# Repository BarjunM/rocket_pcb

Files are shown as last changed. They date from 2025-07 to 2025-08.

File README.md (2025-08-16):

# Elytra: TVC Hobby Rocket Flight Computer

## Short Description

Elytra is a half-kilogram solid-fuel TVC hobby rocket flight computer. To develop a custom computer, the goal is to start as simple as possible and iterate through more and more detailed developments. The current version thus far incorporates working components including an ESP32, BMP280, and MPU6050 dev board and joins them all onto 1 single pcb.

## Why Make This Project?

The purpose of Elytra is to eventually explore self-landing rocket technology. In order to develop an autonomous rocket, the computer needs to be able to read input data regarding yaw, pitch, roll, acceleration, and elevation in order to actively adjust the direction of thrust and self-correct direction. Hence, the purpose of the flight computer is to actively control a thrust vectoring system via servos (TVC) based on input data from various telemetry sensors, including an accelerometer (mpu6050) and barometer (bmp280)

video demo: https://youtu.be/cWIUwfU-qWE

## Project Images

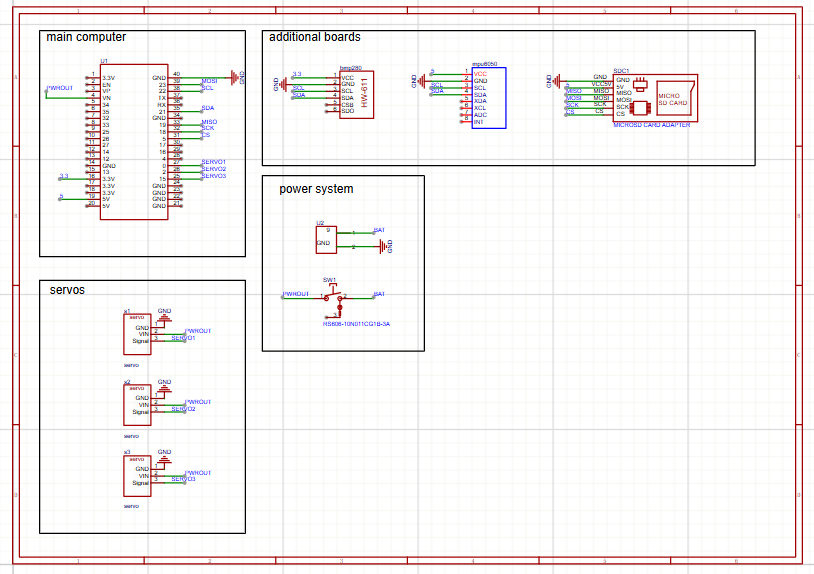
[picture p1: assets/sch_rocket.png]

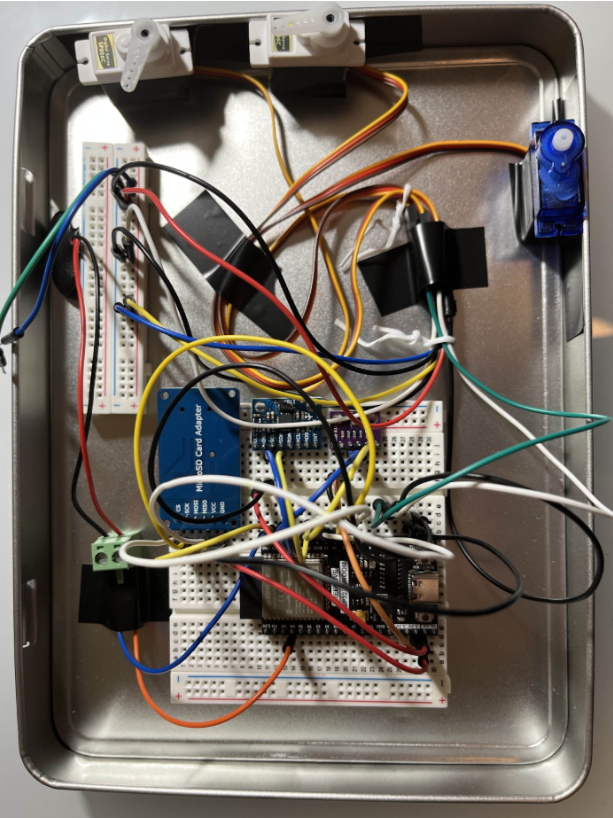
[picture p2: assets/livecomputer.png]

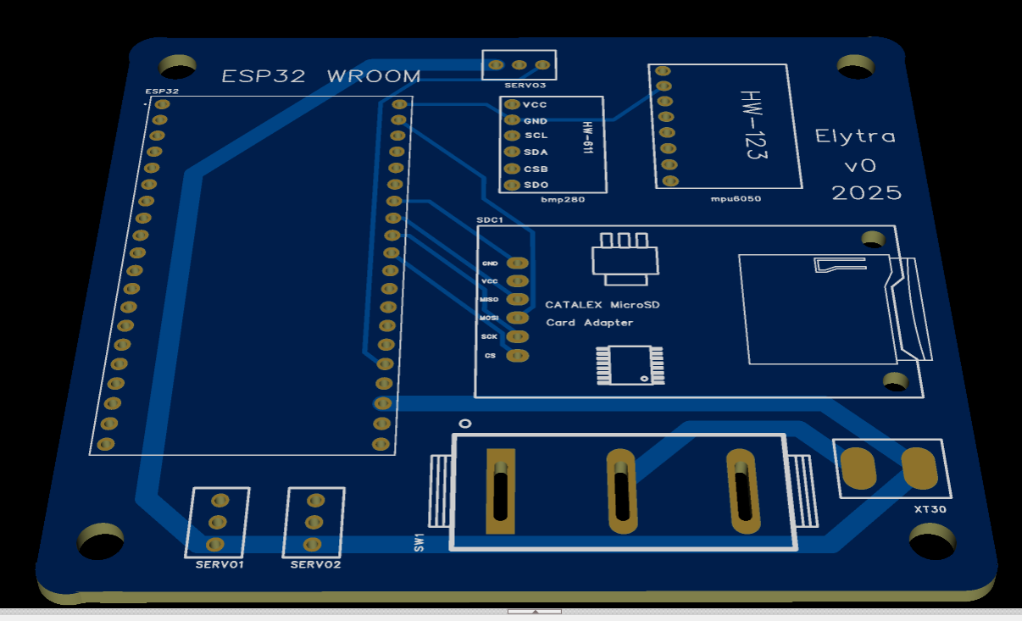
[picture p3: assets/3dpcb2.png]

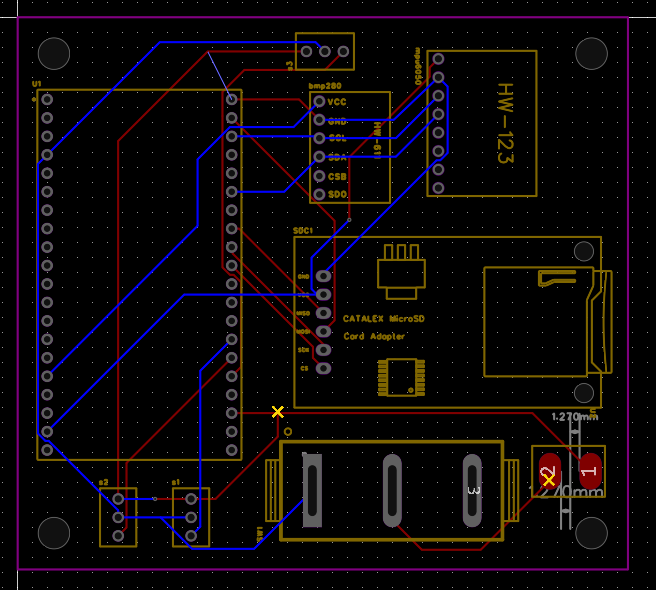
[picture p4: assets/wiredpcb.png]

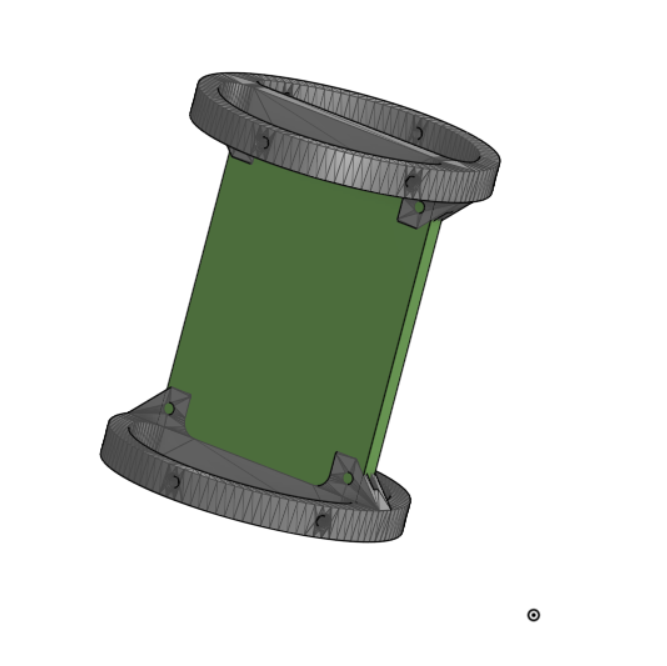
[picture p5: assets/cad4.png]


### Assembly & Test




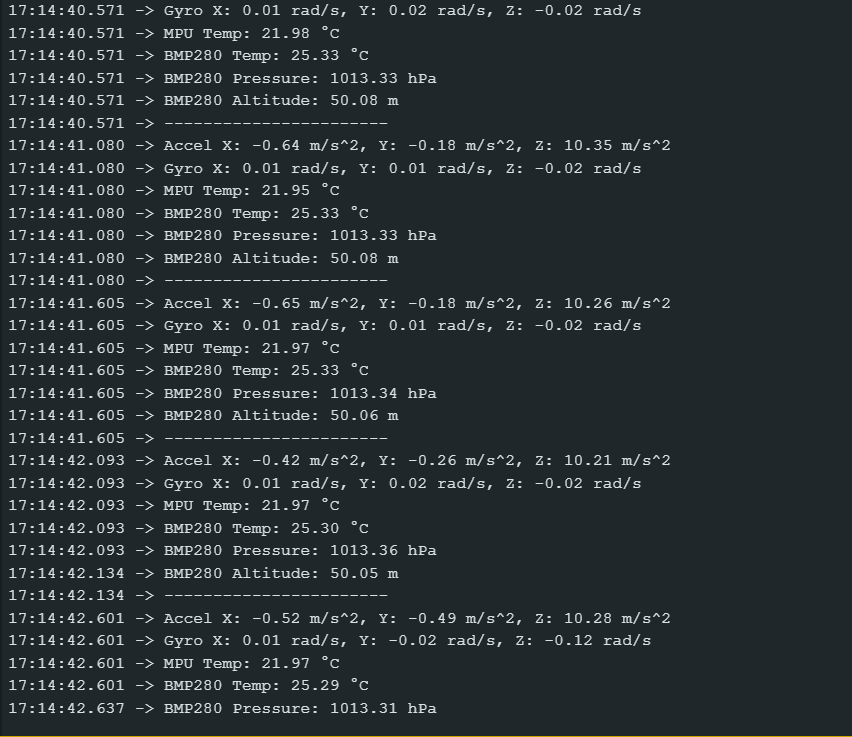
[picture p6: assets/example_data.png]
data


## BOM

| No. | Qty | Component / Comment | Supplier Part | Supplier | Unit Cost | Total Cost (+shipping) | Link |
|-----|-----|---|---|---|---|---|---|
| 1 | 5 | RS606-10N011CG1B-3A | C2885789 | LCSC | $0.67* | $3.35* | [JLCPCB](https://jlcpcb.com/partdetail/HCTL-RS606101N011CRB/C2885788) |
| 2 | 1 | MPU6050 Breakout (Accelerometer) | - | AliExpress | - | Already Owned | - |
| 3 | 1 | BMP280 Breakout (Barometer) | - | AliExpress | - | Already Owned | - |
| 4 | 1 | ESP32 WROOM (Microcontroller) | - | AliExpress | - | Already Owned | - |
| 5 | 1 | Micro SD Card Reader (Data Storage)  | - | AliExpress | - | Already Owned | - |
| 6 | 1 | Servos (Motor) | - | AliExpress | - | Already Owned | - |
| 7 | 1 | 3S LiPo (Battery) | - | AliExpress | - | Already Owned | - |
| 8 | 5 | 3S XT30 to 5V 5A (Buck Converter) | - | SpeedyFPV  | - | Already Owned | - |
| 9 | 5 | Custom PCB | - | JLCPCB | $2.92 | $14.60 + $27.72 shipping| - |

**Total Cost: $45.67** (excluding already owned components)

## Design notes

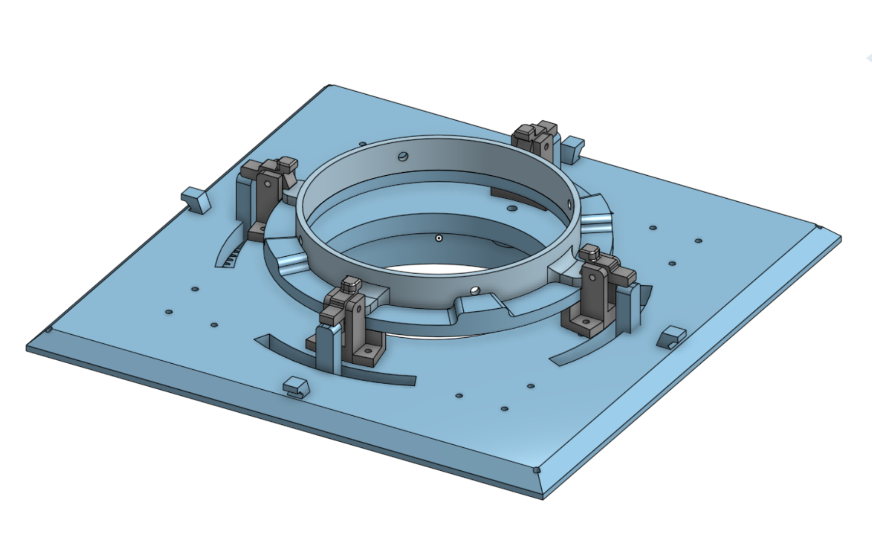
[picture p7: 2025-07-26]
assets/cad2.png

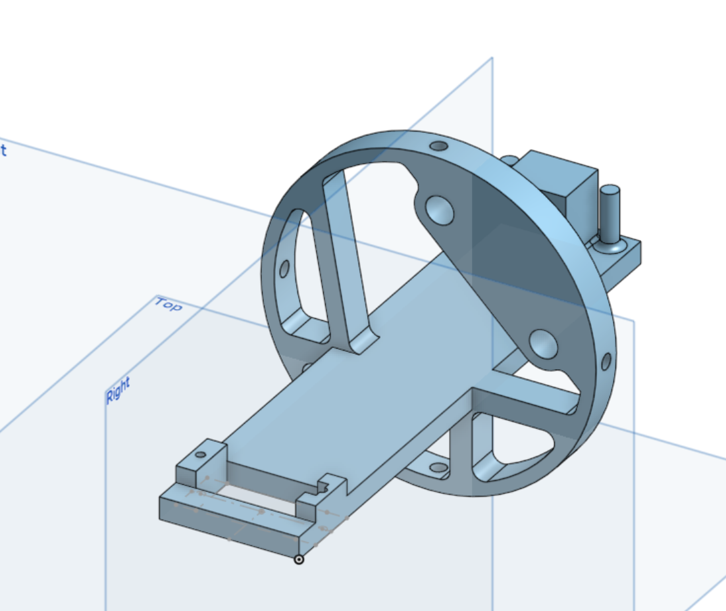
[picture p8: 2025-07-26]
assets/cad1.png

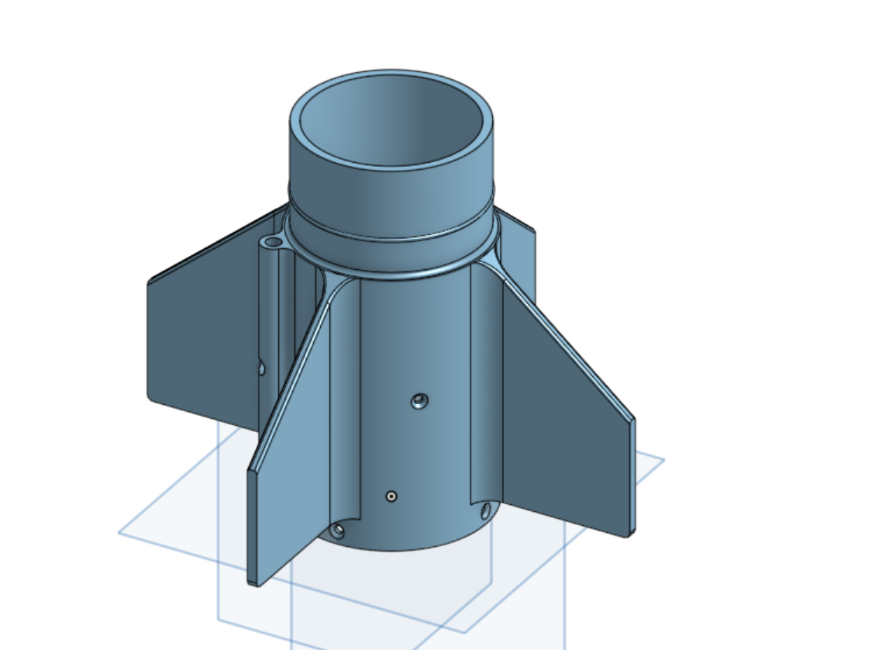
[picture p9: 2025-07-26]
assets/cad3.png

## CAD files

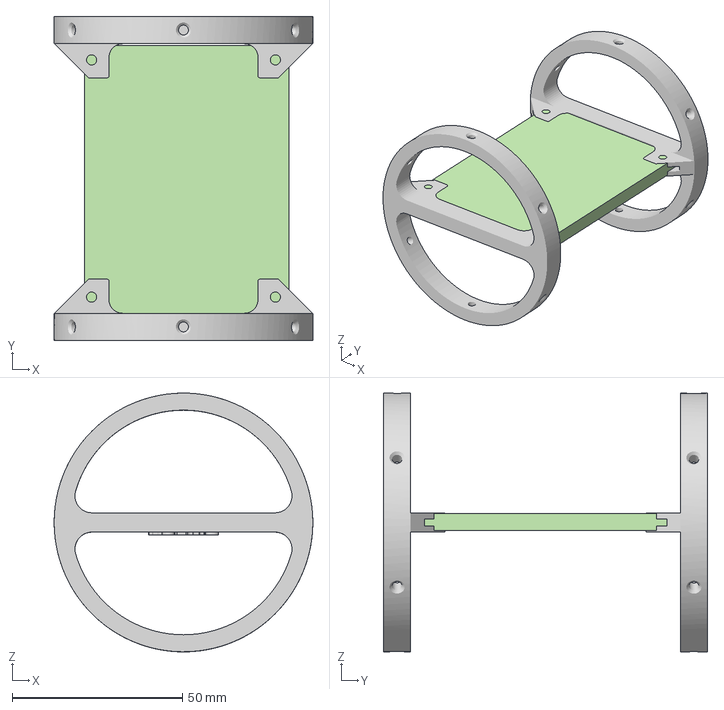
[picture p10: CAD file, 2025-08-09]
CAD/Mount_NEW.step
76.0 x 95.2 x 76.0 mm

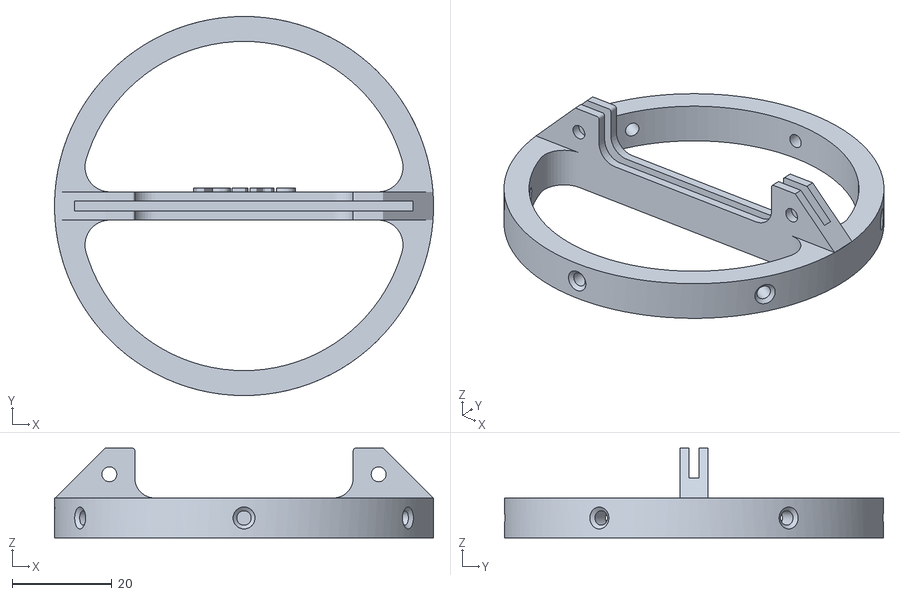
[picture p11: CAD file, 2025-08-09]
PRODUCTION/mount_pcb.stl
76.0 x 76.0 x 18.0

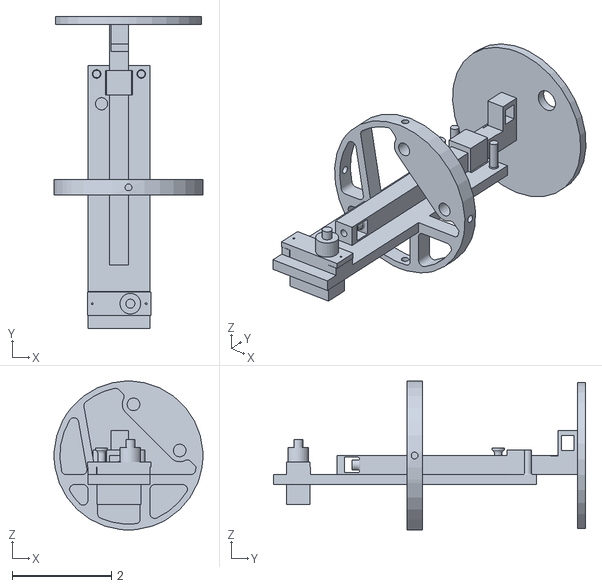
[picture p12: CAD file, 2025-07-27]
PRODUCTION/Mount.stl
3.00 x 6.28 x 3.00

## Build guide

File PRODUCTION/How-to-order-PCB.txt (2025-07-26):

How to Order PCB

Please refer to:
https://prodocs.easyeda.com/en/pcb/order-order-pcb/index.html

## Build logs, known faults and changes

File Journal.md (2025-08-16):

---
title: "Elytra"
author: "Arjun Gupta (On Slack: Arjun H)"
description: "Elytra is a half-kilogram solid-fuel TVC hobby rocket flight computer"
created_at: "2025-07-25"
---

**Daily Journal, Total time 17 hours**

## July 18 (4 hours): Research begins!

Today was a sunny afternoon so I decided to catch some shade and look at some flight  
computer parts. Since I’ve never made a pcb before, I checked out a couple of videos from BPS  
space and instantly got confused… An overview of researched systems include: some sort of  
accelerometer in order to track active trajectory in 3d space - decided on mpu6050, a barometer  
to track altitude - decided on bmp280, a flight computer - esp32 is great since it has wireless  
capability, and sd storage. Since batteries seem pretty expensive, it looks like I should be able  
to power the whole thing with a 9 volt battery.  

In order to get this thing to just work ASAP, I’ve found a bunch of breakoutboards which I can  
link together though a PCB and which will also be able to mount 3 servo motors to: 2 for the  
TVC gimbal, and one for a parachute system.

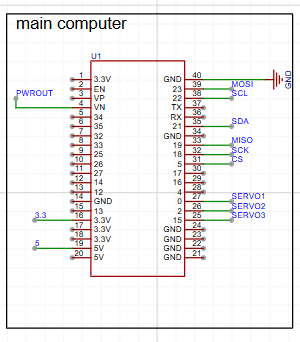
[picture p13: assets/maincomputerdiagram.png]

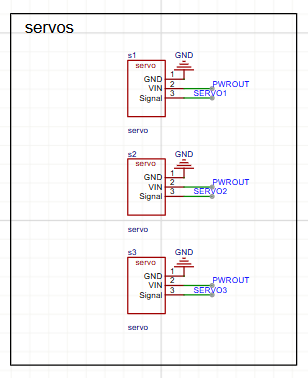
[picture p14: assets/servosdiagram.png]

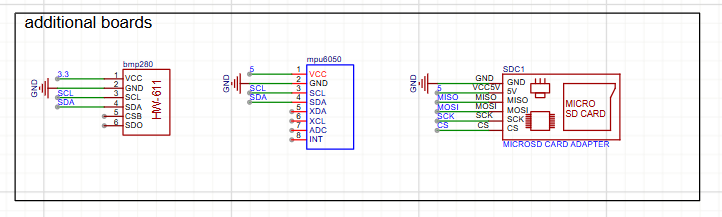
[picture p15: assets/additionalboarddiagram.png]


## July 23 (5 hours): There's always that one thing that smacks you in the face

After ordering everything and slapping everything together on a breadboard, a couple  
realisations slipped my mind. I just realised that a single 9 volt battery will probability not be able  
to provide enough current to 3 servos under load while also powering the esp32 breakout board  
(~0.5 amp for each motor + 200 mA for the esp32 is a little to close to the ~0.8 mA continuous  
to ~2 A max draw for any general 9v battery).  

I found this 3s lipo from BetaFPV - which also exists on aliexpress  
[https://betafpv.com/collections/batt-3s/products/lava-2s-3s-4s-450mah-75c-battery-2pcs?variant=40376192663686](https://betafpv.com/collections/batt-3s/products/lava-2s-3s-4s-450mah-75c-battery-2pcs?variant=40376192663686)  
which should pair nicely with this 12v to 5v buck converter module with an xt30 connector  
[https://speedyfpv.com/products/readytosky-5v-ubec-3a-5a-7a-lipo-dc-dc-voltage-converter-step-down-module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](https://speedyfpv.com/products/readytosky-5v-ubec-3a-5a-7a-lipo-dc-dc-voltage-converter-step-down-module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)  
it's only 5$ so def worth it.  

Troubleshooting took quite a bit, I didn’t understand why the schematic didn’t convert to pcb at  
first, then I quickly found out that not all public components actually have component footprints!  
So I had to make a few and resize a couple of the boards before proceeding. Since I am mostly  
using breakoutboards, the footprints are really only a bunch of multi-layer pads.


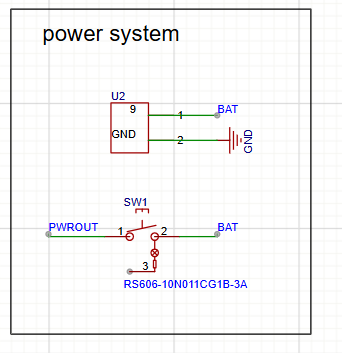
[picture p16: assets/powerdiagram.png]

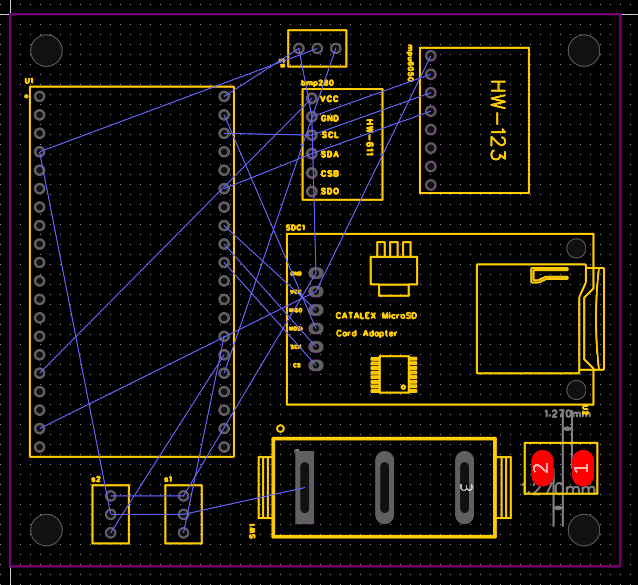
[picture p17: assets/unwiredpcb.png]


## July 24 (2 hours): This takes longer than it looks…

Routing is annoying as you want everything to look nice… but it has to actually work. Just spent  
time making it look not trash. Also touched up some of the component footprints and made them  
so they wouldn’t be a huge pain to solder to.


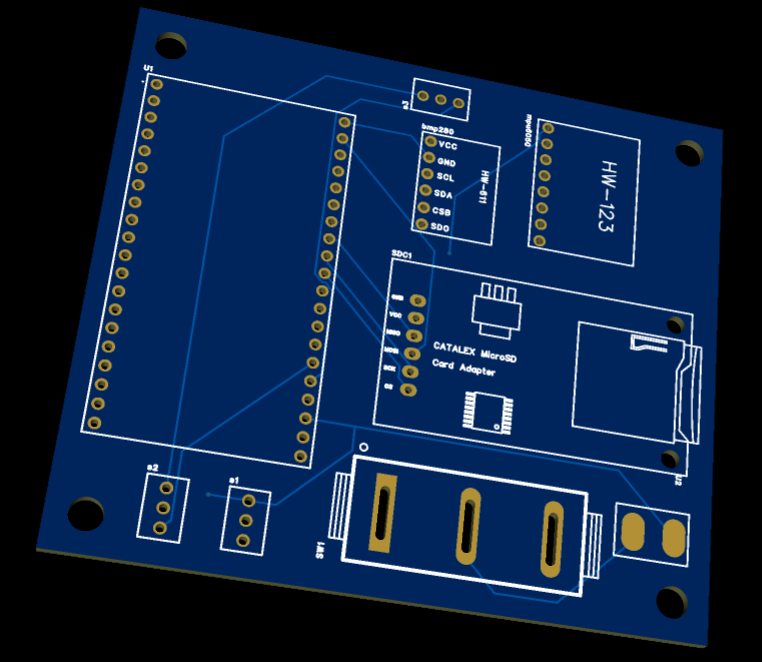
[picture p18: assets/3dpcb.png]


## August 7: PCBs
Got the shipping notice for the boards today. Double‑checked the footprints list & soldering order so I wouldn't waste time once the package landed. Gathered flux, tips, wick, headers, and queued up the continuity checklist. (No real time counted, just logistics.)

## August 8 (2.5 hours): Solder marathon & power bring‑up

Unboxed everything and went straight into assembly. Started with the lowest‑profile components / headers, then sensor breakout boards (mpu6050, bmp280, SD module, ESP32 headers). Lots of careful flux + drag soldering so I wouldn't lift pads on the custom footprints. After each section I buzzed out traces: 3V3, 5V, GND rails, I2C lines, SPI lines to the SD, and servo signal pins. No shorts (yay), only had to reflow one stubborn SDA joint.

Brought up the power system: verified buck output at 5.02 V under a light dummy load and checked that the ESP32 3V3 regulator stayed within spec. All sensors enumerated on the bus first try. Servos started up with a quick test.





## August 9–10 (3.5 hours): Sensor validation, PID + TVC sim tuning

Spent time writing bring‑up / test sketches: read mpu6050 accel + gyro, fused with a quick complementary filter; grabbed bmp280 pressure -> altitude deltas; confirmed SD init + logged a short sensor stream. Added error handling to catch any I2C hiccups (none so far). 

[TVC + PID demo video](/assets/FC.MOV)  

Then moved into PID + thrust vector control simulation, fed in some synthetic disturbance profiles and iterated gains until response settled without overshoot while keeping rise time snappy. Also mapped servo pulse limits to physical gimbal angles so the controller output clamps cleanly.

data

Ran a few full-loop software runs (sensor -> filter -> PID -> actuator mapping) and everything behaved; timing headroom on the ESP32 looks fine.

Local demo video file: [Elytra basic demo](/assets/Elytra_Basic.mp4)

YouTube demo: https://youtu.be/cWIUwfU-qWE
Reddit post: https://www.reddit.com/r/ArjunsWorld/comments/1mqmt3m/first_pcb_elytra/

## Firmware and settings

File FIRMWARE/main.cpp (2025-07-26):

#include <Wire.h>
#include <SPI.h>
#include <SD.h>
#include <Servo.h>
#include <Adafruit_MPU6050.h>
#include <Adafruit_BMP280.h>
#include <Adafruit_Sensor.h>

#define SERVO_X_PIN 9
#define SERVO_Y_PIN 10
#define SD_CS_PIN 4
#define BUZZER_PIN 8
#define LED_PIN 13
#define PYRO_1_PIN 5
#define PYRO_2_PIN 6

#define SAMPLE_FREQ 200.0f
#define BETA_INIT 0.1f 

Adafruit_MPU6050 mpu;
Adafruit_BMP280 bmp;
Servo servoX;
Servo servoY;
File dataFile;

enum FlightState {
    STATE_POWER_ON,
    STATE_IDLE,
    STATE_ARMED,
    STATE_FLIGHT_ASCENT,
    STATE_FLIGHT_BURNOUT,
    STATE_COAST,
    STATE_APOGEE_DETECTED,
    STATE_DESCENT_DROGUE,
    STATE_DESCENT_MAIN,
    STATE_LANDED,
    STATE_ABORT
};

FlightState currentState = STATE_POWER_ON;

volatile float q0 = 1.0f, q1 = 0.0f, q2 = 0.0f, q3 = 0.0f;
volatile float beta = BETA_INIT;

float roll, pitch, yaw;
float accX, accY, accZ, accMagnitude;
float gyroX, gyroY, gyroZ;

float initialAltitude = 0.0f;
float currentAltitude = 0.0f;
float maxAltitude = 0.0f;
float pressure, temperature;

float setpointPitch = 0.0f;
float setpointRoll = 0.0f;

double pid_pitch_p, pid_pitch_i, pid_pitch_d;
double pid_roll_p, pid_roll_i, pid_roll_d;

double Kp = 3.0;
double Ki = 0.05;
double Kd = 1.2;

float lastPitchError = 0.0f;
float lastRollError = 0.0f;
float integralPitch = 0.0f;
float integralRoll = 0.0f;

unsigned long loopTimer;
unsigned long launchTime = 0;
unsigned long burnoutTime = 0;
unsigned long apogeeTime = 0;
unsigned long lastStateChangeTime = 0;

const int servoX_center = 90;
const int servoY_center = 90;
const int servo_max_deflection = 20;

void madgwickAHRSupdateIMU(float gx, float gy, float gz, float ax, float ay, float az);
void updateSensors();
void updateStateMachine();
void tvcControl();
void logData();
void setStatusLED(int r, int g, int b);
void buzz(int freq, int duration);

void setup() {
    Serial.begin(115200);
    Wire.begin();

    pinMode(LED_PIN, OUTPUT);
    pinMode(BUZZER_PIN, OUTPUT);
    pinMode(PYRO_1_PIN, OUTPUT);
    pinMode(PYRO_2_PIN, OUTPUT);
    digitalWrite(PYRO_1_PIN, LOW);
    digitalWrite(PYRO_2_PIN, LOW);

    if (!mpu.begin()) {
        Serial.println("MPU6050 connection failed");
        currentState = STATE_ABORT;
        while (1) { buzz(200, 500); delay(500); }
    }
    mpu.setAccelerometerRange(MPU6050_RANGE_16_G);
    mpu.setGyroRange(MPU6050_RANGE_500_DEG);
    mpu.setFilterBandwidth(MPU6050_BAND_44_HZ);

    if (!bmp.begin()) {
        Serial.println("BMP280 connection failed");
        currentState = STATE_ABORT;
        while (1) { buzz(300, 500); delay(500); }
    }
    bmp.setSampling(Adafruit_BMP280::MODE_NORMAL,
                    Adafruit_BMP280::SAMPLING_X2,
                    Adafruit_BMP280::SAMPLING_X16,
                    Adafruit_BMP280::FILTER_X16,
                    Adafruit_BMP280::STANDBY_MS_0_5);

    servoX.attach(SERVO_X_PIN);
    servoY.attach(SERVO_Y_PIN);
    servoX.write(servoX_center);
    servoY.write(servoY_center);

    if (!SD.begin(SD_CS_PIN)) {
        Serial.println("SD card initialization failed");
    } else {
        dataFile = SD.open("datalog.csv", FILE_WRITE);
        if (dataFile) {
            dataFile.println("Time,State,Altitude,MaxAlt,Pressure,Temp,Roll,Pitch,Yaw,AccX,AccY,AccZ,GyroX,GyroY,GyroZ,ServoX,ServoY,q0,q1,q2,q3");
            dataFile.close();
        }
    }
    
    buzz(1000, 100); delay(100); buzz(1000, 100);
    
    float tempAlt = 0;
    for(int i=0; i<100; i++){
        tempAlt += bmp.readAltitude(1013.25);
        delay(10);
    }
    initialAltitude = tempAlt / 100.0;
    maxAltitude = initialAltitude;

    currentState = STATE_IDLE;
    lastStateChangeTime = millis();
    loopTimer = micros();
}

void loop() {
    updateSensors();
    madgwickAHRSupdateIMU(gyroX, gyroY, gyroZ, accX, accY, accZ);
    updateStateMachine();
    logData();
    
    while(micros() - loopTimer < (1000000.0f / SAMPLE_FREQ));
    loopTimer = micros();
}

void updateSensors() {
    sensors_event_t a, g, temp;
    mpu.getEvent(&a, &g, &temp);

    accX = a.acceleration.x;
    accY = a.acceleration.y;
    accZ = a.acceleration.z;
    accMagnitude = sqrt(accX*accX + accY*accY + accZ*accZ);

    gyroX = g.gyro.x;
    gyroY = g.gyro.y;
    gyroZ = g.gyro.z;

    pressure = bmp.readPressure();
    temperature = bmp.readTemperature();
    currentAltitude = bmp.readAltitude(1013.25) - initialAltitude;

    yaw   = atan2(2.0f * (q1 * q2 + q0 * q3), q0 * q0 + q1 * q1 - q2 * q2 - q3 * q3) * 57.29578f;
    pitch = -asin(2.0f * (q1 * q3 - q0 * q2)) * 57.29578f;
    roll  = atan2(2.0f * (q0 * q1 + q2 * q3), q0 * q0 - q1 * q1 - q2 * q2 + q3 * q3) * 57.29578f;
}

void updateStateMachine() {
    unsigned long now = millis();

    switch (currentState) {
        case STATE_IDLE:
            if (accMagnitude > 30.0f) { 
                currentState = STATE_ARMED;
            }
            servoX.write(servoX_center);
            servoY.write(servoY_center);
            break;

        case STATE_ARMED:
            if (accMagnitude > 40.0f && currentAltitude > 20.0f) {
                currentState = STATE_FLIGHT_ASCENT;
                launchTime = now;
            }
            break;

        case STATE_FLIGHT_ASCENT:
            tvcControl();
            if (accMagnitude < 8.0f && (now - launchTime > 1500)) {
                currentState = STATE_FLIGHT_BURNOUT;
                burnoutTime = now;
            }
            if (currentAltitude > maxAltitude) maxAltitude = currentAltitude;
            break;

        case STATE_FLIGHT_BURNOUT:
            tvcControl();
            if (currentAltitude < maxAltitude - 10.0f) {
                currentState = STATE_APOGEE_DETECTED;
                apogeeTime = now;
            }
            if (currentAltitude > maxAltitude) maxAltitude = currentAltitude;
            break;

        case STATE_COAST:
            servoX.write(servoX_center);
            servoY.write(servoY_center);
            if (currentAltitude < maxAltitude - 10.0f) {
                currentState = STATE_APOGEE_DETECTED;
                apogeeTime = now;
            }
            if (currentAltitude > maxAltitude) maxAltitude = currentAltitude;
            break;

        case STATE_APOGEE_DETECTED:
            servoX.write(servoX_center);
            servoY.write(servoY_center);
            digitalWrite(PYRO_1_PIN, HIGH); 
            buzz(2000, 500);
            currentState = STATE_DESCENT_DROGUE;
            break;

        case STATE_DESCENT_DROGUE:
            if (currentAltitude < 400.0f) {
                digitalWrite(PYRO_2_PIN, HIGH);
                buzz(2000, 500);
                currentState = STATE_DESCENT_MAIN;
            }
            break;

        case STATE_DESCENT_MAIN:
            if (abs(currentAltitude - initialAltitude) < 5.0f && accMagnitude < 2.0f) {
                currentState = STATE_LANDED;
            }
            break;

        case STATE_LANDED:
            digitalWrite(PYRO_1_PIN, LOW);
            digitalWrite(PYRO_2_PIN, LOW);
            buzz(1500, 2000);
            break;
        
        case STATE_ABORT:
            break;
    }
}

void tvcControl() {
    float pitchError = setpointPitch - pitch;
    float rollError = setpointRoll - roll;

    integralPitch += Ki * pitchError;
    integralRoll += Ki * rollError;
    integralPitch = constrain(integralPitch, -100, 100);
    integralRoll = constrain(integralRoll, -100, 100);

    float pitchDerivative = pitchError - lastPitchError;
    float rollDerivative = rollError - lastRollError;
    lastPitchError = pitchError;
    lastRollError = rollError;

    float pitchOutput = Kp * pitchError + integralPitch + Kd * pitchDerivative;
    float rollOutput = Kp * rollError + integralRoll + Kd * rollDerivative;

    int servoX_angle = servoX_center + constrain(rollOutput, -servo_max_deflection, servo_max_deflection);
    int servoY_angle = servoY_center + constrain(pitchOutput, -servo_max_deflection, servo_max_deflection);

    servoX.write(servoX_angle);
    servoY.write(servoY_angle);
}

void logData() {
    dataFile = SD.open("datalog.csv", FILE_WRITE);
    if (dataFile) {
        dataFile.print(millis()); dataFile.print(",");
        dataFile.print(currentState); dataFile.print(",");
        dataFile.print(currentAltitude, 2); dataFile.print(",");
        dataFile.print(maxAltitude, 2); dataFile.print(",");
        dataFile.print(pressure, 2); dataFile.print(",");
        dataFile.print(temperature, 2); dataFile.print(",");
        dataFile.print(roll, 2); dataFile.print(",");
        dataFile.print(pitch, 2); dataFile.print(",");
        dataFile.print(yaw, 2); dataFile.print(",");
        dataFile.print(accX, 4); dataFile.print(",");
        dataFile.print(accY, 4); dataFile.print(",");
        dataFile.print(accZ, 4); dataFile.print(",");
        dataFile.print(gyroX, 4); dataFile.print(",");
        dataFile.print(gyroY, 4); dataFile.print(",");
        dataFile.print(gyroZ, 4); dataFile.print(",");
        dataFile.print(servoX.read()); dataFile.print(",");
        dataFile.print(servoY.read()); dataFile.print(",");
        dataFile.print(q0, 4); dataFile.print(",");
        dataFile.print(q1, 4); dataFile.print(",");
        dataFile.print(q2, 4); dataFile.print(",");
        dataFile.println(q3, 4);
        dataFile.close();
    }
}

void buzz(int freq, int duration) {
    tone(BUZZER_PIN, freq, duration);
}

void madgwickAHRSupdateIMU(float gx, float gy, float gz, float ax, float ay, float az) {
	float recipNorm;
	float s0, s1, s2, s3;
	float qDot1, qDot2, qDot3, qDot4;
	float _2q0, _2q1, _2q2, _2q3, _4q0, _4q1, _4q2 ,_8q1, _8q2, q0q0, q1q1, q2q2, q3q3;

	float dt = (float)(micros() - loopTimer) / 1000000.0f;
    if(dt == 0) return;

	qDot1 = 0.5f * (-q1 * gx - q2 * gy - q3 * gz);
	qDot2 = 0.5f * (q0 * gx + q2 * gz - q3 * gy);
	qDot3 = 0.5f * (q0 * gy - q1 * gz + q3 * gx);
	qDot4 = 0.5f * (q0 * gz + q1 * gy - q2 * gx);

	if(!((ax == 0.0f) && (ay == 0.0f) && (az == 0.0f))) {
		recipNorm = 1.0f / sqrt(ax * ax + ay * ay + az * az);
		ax *= recipNorm;
		ay *= recipNorm;
		az *= recipNorm;

		_2q0 = 2.0f * q0;
		_2q1 = 2.0f * q1;
		_2q2 = 2.0f * q2;
		_2q3 = 2.0f * q3;
		_4q0 = 4.0f * q0;
		_4q1 = 4.0f * q1;
		_4q2 = 4.0f * q2;
		_8q1 = 8.0f * q1;
		_8q2 = 8.0f * q2;
		q0q0 = q0 * q0;
		q1q1 = q1 * q1;
		q2q2 = q2 * q2;
		q3q3 = q3 * q3;

		s0 = _4q0 * q2q2 + _2q2 * ax + _4q0 * q1q1 - _2q1 * ay;
		s1 = _4q1 * q3q3 - _2q3 * ax + 4.0f * q0q0 * q1 - _2q0 * ay - _4q1 + _8q1 * q1q1 + _8q1 * q2q2 + _4q1 * az;
		s2 = 4.0f * q0q0 * q2 + _2q0 * ax + _4q2 * q3q3 - _2q3 * ay - _4q2 + _8q2 * q1q1 + _8q2 * q2q2 + _4q2 * az;
		s3 = 4.0f * q1q1 * q3 - _2q1 * ax + 4.0f * q2q2 * q3 - _2q2 * ay;
		recipNorm = 1.0f / sqrt(s0 * s0 + s1 * s1 + s2 * s2 + s3 * s3);
		s0 *= recipNorm;
		s1 *= recipNorm;
		s2 *= recipNorm;
		s3 *= recipNorm;

		qDot1 -= beta * s0;
		qDot2 -= beta * s1;
		qDot3 -= beta * s2;
		qDot4 -= beta * s3;
	}

	q0 += qDot1 * dt;
	q1 += qDot2 * dt;
	q2 += qDot3 * dt;
	q3 += qDot4 * dt;

	recipNorm = 1.0f / sqrt(q0 * q0 + q1 * q1 + q2 * q2 + q3 * q3);
	q0 *= recipNorm;
	q1 *= recipNorm;
	q2 *= recipNorm;
	q3 *= recipNorm;
}

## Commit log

2025-07-26 added prod files
    [Drill_NPTH_Through.DRL, Drill_PTH_Through.DRL, Drill_PTH_Through_Via.DRL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]
2025-07-26 added pcb files
2025-07-26 checklist updates
    [BOM.csv]
2025-07-28 fixed format
    [BOM.csv]
2025-08-09 Update pcb files
    [Mount.step]
